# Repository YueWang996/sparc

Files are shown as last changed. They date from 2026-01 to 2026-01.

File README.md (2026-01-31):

<h1 align="center">
  SPARC: Spine with Prismatic and Revolute Compliance for Quadruped Robots
  <br><br>
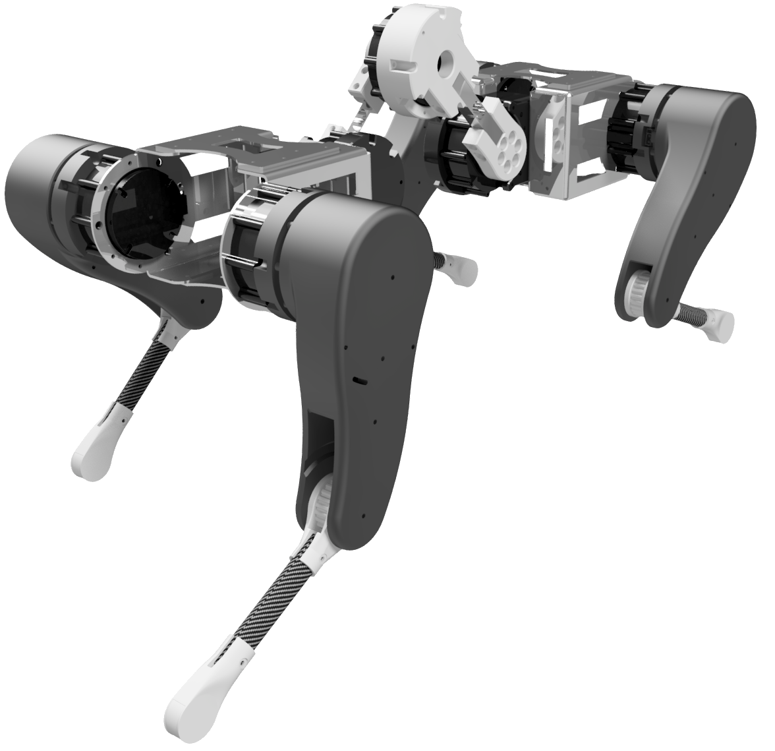
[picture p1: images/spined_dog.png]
SPARC Quadruped
  
  <br>
</h1>

<p align="center">
An open-source 3-DoF sagittal-plane spine module that combines revolute (pitch) and prismatic (axial) motion with programmable task-space impedance for quadruped robots. This repository provides complete hardware designs, circuit schematics, and MuJoCo simulation code for building and testing the SPARC system.
</p>

## Overview

<p align="center">
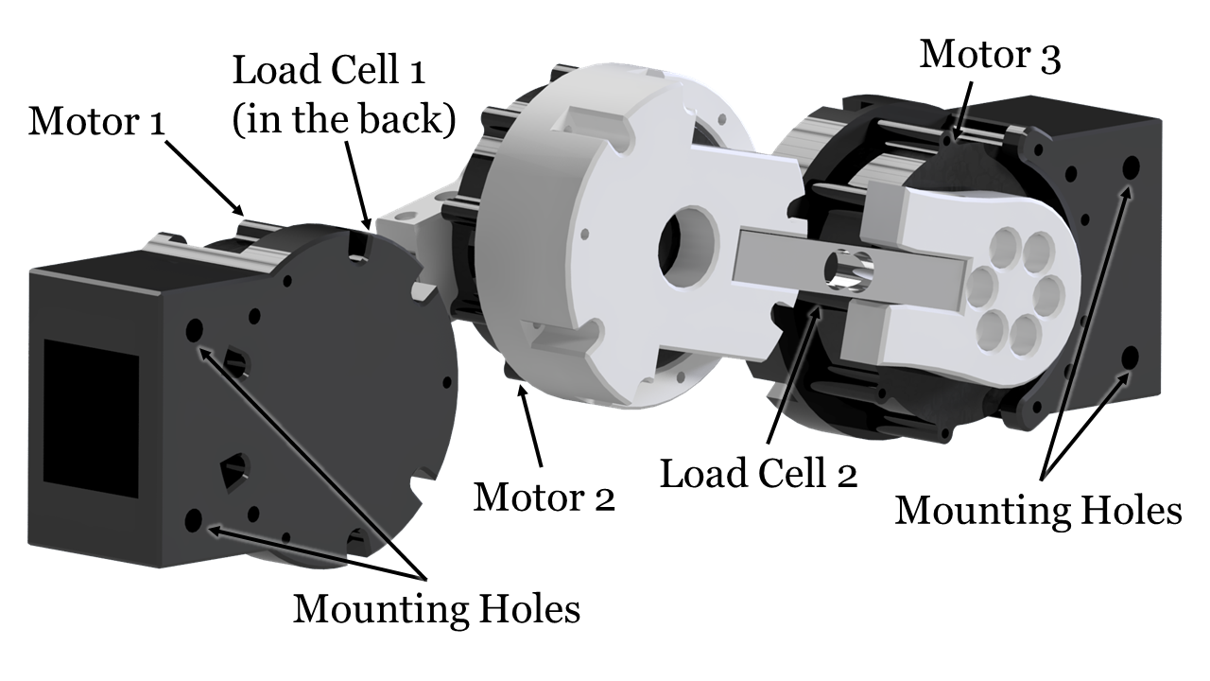
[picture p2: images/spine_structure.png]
SPARC Spine Structure
  
  <br>
  <em>SPARC spine structure with 3-DoF sagittal plane motion</em>
</p>

SPARC is a compact, self-contained spine module (1.26 kg) designed to mount between the fore and hind body segments of quadruped robots. The system integrates three torque-controlled actuators (Xiaomi Cybergear), a 1 kHz motion control board, and protected power electronics in a single package. A floating-base impedance controller with dynamics compensation renders tunable spring-damper behavior along horizontal, vertical, and rotational axes, enabling closed-loop control of both revolute and prismatic degrees of freedom with axis-selective compliance.

## Features

- **3-DoF Sagittal Spine**: Combined revolute (pitch) and prismatic (axial) motion for bio-inspired compliance
- **Task-Space Impedance Control**: Independently tunable stiffness and damping along horizontal, vertical, and rotational axes (validated range: 300-700 N/m horizontal stiffness with ≤1.5% error, R² ≥ 0.992)
- **High-Bandwidth Control**: 1 kHz control loop design with dynamics compensation and Stribeck friction modeling
- **Compact Design**: 1.26 kg package with three quasi-direct-drive actuators (12 N·m peak torque each)
- **Open-Source Hardware**: Complete CAD models and circuit schematics
- **MuJoCo Simulation**: Reference implementation and testing environment for spine compliance effects on locomotion

## Repository Structure

```
sparc/
├── hardware/
│   ├── cad_models_inventor/      # Autodesk Inventor CAD models and assemblies
│   └── circuit_altium_designer/  # Altium Designer circuit schematics and PCB layouts
├── mujoco_simulation/
│   ├── asset/                    # URDF/XML models and STL meshes
│   ├── spine_impedance_controller.py  # Task-space impedance controller implementation
│   ├── main_spine.py             # Basic spine simulation
│   ├── main_robot_raibert.py     # Quadruped bounding gait simulation
│   ├── dog_controller_raibert.py # Quadruped leg controller
│   └── mujoco_interface.py       # MuJoCo simulation interface
├── images/                       # Project images and diagrams
├── LICENSE                       # MIT License
└── README.md                     # This file
```

## Hardware Design

<p align="center">
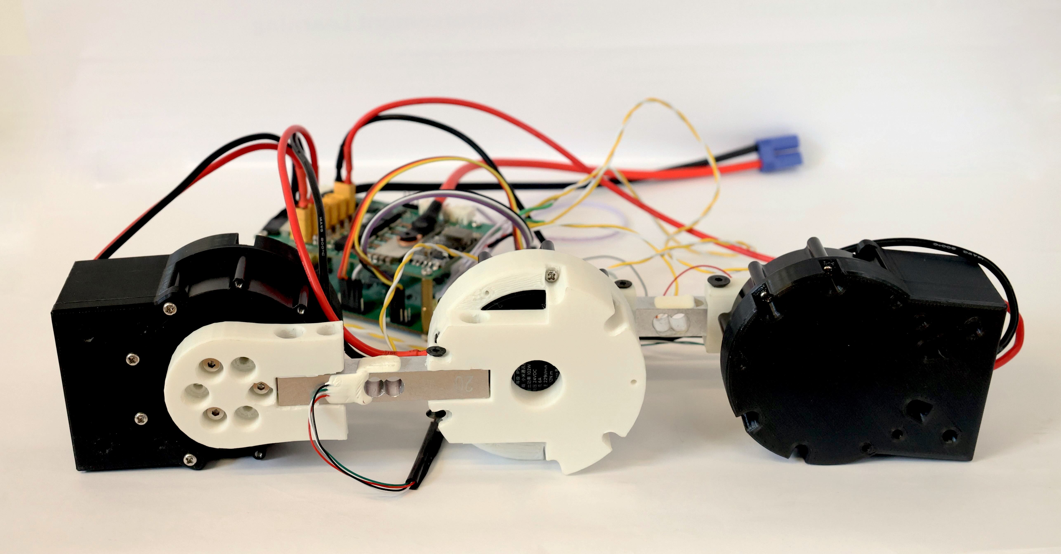
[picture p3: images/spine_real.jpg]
SPARC Hardware Prototype
  
  <br>
  <em>SPARC hardware prototype with integrated actuators and electronics</em>
</p>

The `hardware/` directory contains complete mechanical and electrical designs ready for fabrication:

- **CAD Models** ([cad_models_inventor/](hardware/cad_models_inventor/)): Autodesk Inventor files with complete spine assembly, 3D-printed links, and mounting interfaces for quadruped integration
- **Circuit Schematics** ([circuit_altium_designer/](hardware/circuit_altium_designer/)): Altium Designer project files for Motion Control Board (MCB) and Power Management Unit (PMU)

### Key Components

- **Actuators**: 3× Xiaomi Cybergear quasi-direct-drive motors (12 N·m peak torque, CAN bus interface)
- **Motion Control Board (MCB)**:
  - STM32F405RGT6 microcontroller (@168 MHz) (Note: this will be upgraded to STM32G473 shortly)
  - CAN transceiver for multi-actuator communication
  - Onboard 6-axis IMU for attitude estimation
  - USB interface for parameter tuning and debugging
- **Power Management Unit (PMU)**:
  - Input: 6S LiPo (22.2V nominal) or 24V bench supply
  - Over-current protection and thermal monitoring
  - Filtered power distribution to MCB and actuators
- **Sensing (Optional)**:
  - 2× load cells on central links for direct torque measurement
  - Magnetic encoders integrated in Cybergear actuators (14-bit resolution)
- **Structure**:
  - Lightweight 3D-printed links (PLA/PETG)
  - Mass distribution: 75% concentrated at actuators to minimize reflected inertia
  - Total spine mass: 1.26 kg

**Note**: Control software needs to be developed based on your specific requirements and the impedance control algorithms demonstrated in the simulation code.

## MuJoCo Simulation

The `mujoco_simulation/` directory provides simulation environments for testing and developing control algorithms for the SPARC spine.

### Available Simulations

1. **Basic Spine Simulation** ([main_spine.py](mujoco_simulation/main_spine.py))
   - Standalone spine characterization with manual displacement tests
   - Task-space impedance controller demonstration across 300-700 N/m stiffness range
   - Generates quasi-static force-displacement curves and dynamic step responses
   - Ideal for controller tuning and parameter exploration

2. **Quadruped Bounding Gait** ([main_robot.py](mujoco_simulation/main_robot.py))
   - Full 8-DoF quadruped robot with integrated SPARC spine
   - Bounding gait generator with configurable frequency, stride length, and step height
   - Real-time spine compliance adjustment during locomotion
   - Cost of transport optimization demonstrations
   - Supports terrain slope variation for performance analysis

### Simulation Features

- **Physics-accurate dynamics**: Task-space impedance control using batched CRBA/RNEA algorithms via [bard-pytorch-dynamics](https://github.com/YueWang996/bard-pytorch-dynamics)
- **Friction modeling**: Smooth Stribeck compensation for realistic low-velocity behavior
- **Complete robot models**: URDF files with inertial parameters and collision geometries
- **Real-time visualization**: Interactive MuJoCo viewer with parameter adjustment
- **Data logging**: CSV export for post-analysis and plotting

The simulation code provides a reference implementation of the impedance control algorithms that can be adapted for embedded systems.

## Getting Started

### Prerequisites

- Python 3.8+
- [MuJoCo](https://mujoco.org/) (for physics simulation)
- [bard-pytorch-dynamics](https://github.com/YueWang996/bard-pytorch-dynamics) (batched articulated robot dynamics solver)

### Installation

1. **Clone the repository**
   ```bash
   git clone https://github.com/YueWang996/sparc.git
   cd sparc
   ```

2. **Install MuJoCo**

   Follow the official [MuJoCo installation guide](https://mujoco.readthedocs.io/en/stable/programming/index.html#getting-started).

3. **Install bard-pytorch-dynamics**

   Follow the installation instructions at the [bard-pytorch-dynamics repository](https://github.com/YueWang996/bard-pytorch-dynamics.git):
   ```bash
   git clone https://github.com/YueWang996/bard-pytorch-dynamics.git
   cd bard-pytorch-dynamics
   # Follow the specific installation steps in that repository's README
   ```

4. **Install additional Python dependencies**
   ```bash
   pip install numpy scipy torch
   ```

### Usage

**Run the basic spine simulation:**
```bash
cd mujoco_simulation
python main_spine.py
```

This launches an interactive MuJoCo viewer where you can manually apply forces to the spine and observe the impedance response. Modify `kx`, `kz`, `kθ` (stiffness) and `dx`, `dz`, `dθ` (damping) parameters in the script to explore different compliance behaviors.

**Run the quadruped bounding gait simulation:**
```bash
cd mujoco_simulation
python main_robot_raibert.py
```

## Building Your Own SPARC

To replicate the hardware:

1. **3D Printing**: Export STL files from the Inventor assemblies in `hardware/cad_models_inventor/` and print using PLA or PETG
2. **PCB Fabrication**: Use the Altium Designer files in `hardware/circuit_altium_designer/` to generate Gerber files for PCB manufacturing
3. **Component Sourcing**:
   - 3× Xiaomi Cybergear motors (available from Xiaomi robotics distributors)
   - 2× Load cells (e.g., TAL220 10kg or similar)
   - STM32F405RGT6 microcontroller and supporting components (see BOM in circuit files. Note, the newer version is using STM32G473 for better performance)
   - 6S LiPo battery or 24V power supply
4. **Assembly**: Follow the CAD assembly structure for mechanical integration
5. **Control Software**: Develop your own control code using the simulation algorithms as reference. The [spine_impedance_controller.py](mujoco_simulation/spine_impedance_controller.py) provides the core impedance control implementation

For detailed build instructions, please refer to the documentation in the `hardware/` subdirectories.

## Performance Characteristics

The SPARC spine has been tested in both hardware benchtop experiments and MuJoCo simulations:

- **Static Stiffness**: Horizontal stiffness control from 300-700 N/m with high linearity (R² ≥ 0.992) across ±60 mm displacement range
- **Dynamic Response**: Tunable damping behavior from 0-40 N·s/m with predictable settling characteristics
- **Axis-Selective Compliance**: Independent control of horizontal, vertical, and rotational stiffness through task-space impedance control
- **Simulation Results**: Terrain-dependent optimal compliance settings:
  - **Downhill slopes**: Higher stiffness (1000-1500 N/m) reduces excessive pitch-down
  - **Flat terrain**: Moderate stiffness (800-1200 N/m) balances efficiency and stability
  - **Uphill slopes**: Lower stiffness (500-1000 N/m) enables elastic energy storage
  - **Optimal stride lengths (70-80 mm)**: Lowest cost of transport with 500-800 N/m stiffness and 8-20 N·s/m damping

These results suggest that adaptive spine compliance can reduce energy costs in quadruped locomotion across varying terrains and gaits.

<!-- ## Citation

If you use this work in your research, please cite:

```bibtex
@article{wang2026sparc,
  title={SPARC: Spine with Prismatic and Revolute Compliance for Quadruped Robots},
  author={Wang, Yue},
  journal={arXiv preprint arXiv:2510.01984},
  year={2026}
}
``` -->

## Applications and Integration

SPARC is designed as a modular component for quadruped robotics research. Potential applications include:

- **Locomotion Research**: Investigate the role of spinal compliance in gait transitions, energy efficiency, and stability
- **Terrain Adaptation**: Study real-time compliance tuning for varying surfaces and slopes
- **Bio-Inspired Robotics**: Explore mammalian spine mechanics in robotic systems
- **Agile Maneuvers**: Leverage spine compliance for jumping, landing, and rapid direction changes
- **Educational Platform**: Teach task-space impedance control and legged robot dynamics

The mounting interface is compatible with common quadruped platforms. Researchers can integrate SPARC by mounting it between fore and hind body segments using the provided bolt pattern.

## Troubleshooting and FAQ

**Q: The simulated spine oscillates excessively at low damping.**
A: Ensure the friction compensation parameters in [spine_impedance_controller.py](mujoco_simulation/spine_impedance_controller.py) match your system. Slight over-compensation can cause instability at `dx = 0`. Increase damping to `dx ≥ 2` N·s/m for stable operation.

**Q: How do I implement the controller on hardware?**
A: Use the simulation code in [spine_impedance_controller.py](mujoco_simulation/spine_impedance_controller.py) as a reference for implementing the task-space impedance control on your embedded system. The core algorithms (CRBA/RNEA, Jacobian computation, friction compensation) can be adapted to C/C++ for real-time execution.

**Q: Can I use different actuators?**
A: Yes, but you'll need to update the mechanical design to accommodate different motor dimensions and mounting patterns, and adapt your control software for different communication protocols.

**Q: What control loop frequency should I target?**
A: The design targets 1 kHz for effective bandwidth up to ~50-100 Hz depending on the commanded stiffness and system configuration.

## Contributing

Contributions are welcome! Areas where community input would be particularly valuable:

- Control software implementations for embedded systems
- Integration guides for specific quadruped platforms
- Additional simulation scenarios and benchmarks
- Experimental validation on different terrains
- Extended control strategies (MPC, reinforcement learning, etc.)

Please open an issue to discuss major changes before submitting pull requests.

## License

This project is licensed under the MIT License - see the [LICENSE](LICENSE) file for details.

<!-- ## Contact

For questions or collaboration opportunities:
- Open an issue in this repository
- GitHub: [@YueWang996](https://github.com/YueWang996) -->

## Acknowledgments

This work is supported by the School of Electronic and Computer Science (ECS), University of Southampton.

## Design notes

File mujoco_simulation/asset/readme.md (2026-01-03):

# Asset Files Documentation

This directory contains robot model files in two different formats for different purposes.

## File Overview

### URDF Files (for bard-pytorch-dynamics library)

URDF (Unified Robot Description Format) files are used with the bard-pytorch-dynamics library for solving robot dynamics problems.

#### `spine.urdf`
- **Purpose**: Defines the spine unit as a standalone component
- **Usage**: Use this file when you need to simulate or analyze the spine mechanism in isolation
- **Library**: bard-pytorch-dynamics

#### `spined_dog.urdf`
- **Purpose**: Defines a quadruped dog robot with the spine integrated into its body
- **Usage**: Use this file for full-body dynamics simulation with the spine attached to the dog's body
- **Library**: bard-pytorch-dynamics
- **Note**: This model includes full inertia properties for all body parts

#### `spined_dog_spine_dyn.urdf`
- **Purpose**: Defines a quadruped dog robot with the spine integrated, but with simplified leg dynamics
- **Usage**: Use this file when you want to focus on spine dynamics while ignoring leg inertia for computational simplicity
- **Library**: bard-pytorch-dynamics
- **Key Difference**: The spine is attached to the main body of the dog (which retains full inertia since the body is heavy), but the leg inertia is ignored for simplification

### XML Files (for MuJoCo simulation)

XML files are used for MuJoCo (Multi-Joint dynamics with Contact) physics simulation engine.

#### `spine.xml`
- **Purpose**: Defines the spine unit as a standalone component for MuJoCo simulation
- **Usage**: Use this file when simulating the spine mechanism in MuJoCo
- **Physics Engine**: MuJoCo

#### `spined_dog.xml`
- **Purpose**: Defines a quadruped dog robot with the spine integrated for MuJoCo simulation
- **Usage**: Use this file for full-body physics simulation of the spined dog in MuJoCo
- **Physics Engine**: MuJoCo

## Summary Table

| File | Format | Model Type | Purpose | Library/Engine |
|---|---|---|---|---|
| `spine.urdf` | URDF | Spine only | Spine dynamics analysis | bard-pytorch-dynamics |
| `spined_dog.urdf` | URDF | Full dog + spine | Full dynamics with complete inertia | bard-pytorch-dynamics |
| `spined_dog_spine_dyn.urdf` | URDF | Dog + spine (simplified) | Spine-focused dynamics with simplified legs | bard-pytorch-dynamics |
| `spine.xml` | XML | Spine only | Spine MuJoCo simulation | MuJoCo |
| `spined_dog.xml` | XML | Full dog + spine | Full MuJoCo simulation | MuJoCo |

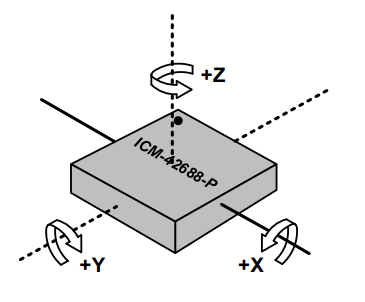
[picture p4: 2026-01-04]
hardware/circuit_altium_designer/motion_control_board/imu.jpg

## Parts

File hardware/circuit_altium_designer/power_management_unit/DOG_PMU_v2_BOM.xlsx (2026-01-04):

Comment | Description | Designator | Footprint | LibRef | Quantity
22uF | VJ1210Y104MXCAT | C1, C2, C3, C4 | C1210 | Capacitor | 4
0.1uF |  | C5, C16, C17, C18, C19 | C0603 | Capacitor | 5
330pF |  | C6 | C0603 | Capacitor | 1
1.5nF |  | C7 | C0603 | Capacitor | 1
10uF | VJ1210Y104MXCAT | C8, C10, C11, C12, C13, C15 | C1210 | Capacitor | 6
1uF | VJ1210Y104MXCAT | C9, C14 | C0603 | Capacitor | 2
5.0SMDJ28A |  | D1 | SMA(DO-214AC) | Diode_Schottky | 1
MBRS3100T3G | Schottky Diodes & Rectifiers 3A 100V | D2 | SMA(DO-214AC) | Diode_Schottky | 1
红灯 0603 | 发光二极管 | D3, D4 | 0603_LED_S1 | 0603 红灯 | 2
B7B-XH-A__LF__SN_ | Connector | J1 | SHDR7W64P0X250_1X7_1990X575X700P | B7B-XH-A__LF__SN_ | 1
5263-3AW |  | J2 | 5264-3AW | 5263-3AW | 1
XH_2.54mm_1x2P |  | J3, J4, J10 | XH2.54mm1x2P弯插 | XH_2.54mm_1x2P | 3
XT30UPB | https://item.taobao.com/item.htm?id=607162270928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 | J5, J6, J8, J9, J11, J12 | XT30UPB | XT30UPB | 6
Header1x4 |  | J7 | Header 1x4p | Header1x4 | 1
KEY_3*4 | C707339 | KEY1 | KEY_3*4 | KEY_3*4 | 1
CSD19536KTT | 100-V N-Channel NexFET™ Power MOSFET | Q1, Q2, Q3, Q4 | KTT0002A | NMOSFET | 4
178kΩ |  | R1 | R0603 | Resistor | 1
5.49kΩ |  | R2 | R0603 | Resistor | 1
10kΩ |  | R3, R12, R13, R14, R15, R16, R17, R32, R33 | R0603 | Resistor | 9
68.1kΩ |  | R4, R5, R6, R7, R8, R9 | R0603 | Resistor | 6
28kΩ |  | R10 | R0603 | Resistor | 1
56kΩ |  | R11 | R0603 | Resistor | 1
1mΩ | CHSA2512R0010F | R18, R19, R20, R21, R22 | 2512_R | Resistor | 5
470kΩ |  | R23, R24 | R0603 | Resistor | 2
1kΩ |  | R25 | R0603 | Resistor | 1
10Ω |  | R26, R27, R28, R29 | R0603 | Resistor | 4
NTCS0805E3103JMT | THERMISTOR NTC 10KOHM 3570K 0805 | R30, R31 | NTCS0805_VIS | CMP-02404-000004-2 | 2
10k |  | R34, R35, R36, R37, R38, R39 | R0603 | Resistor | 6
TPS2492PW | The TPS2492 and TPS2493 are easy-to-use, positive high voltage, 14-pin Hotswap Controller | U1 | PW0014A_N | TPS2492PW | 1
TPS5450_module | https://item.taobao.com/item.htm?id=678523742086&spm=a1z0d.6639537&sku_properties=1627207:1665065280 | U2 | TPS5450_module | TPS5450_module | 1
AMS1117-3.3 | C347222 | U3 | SOT-223 | AMS1117-3.3 | 1
STM32C011F6P6 | No Description Available | U4 | TSSOP20_STM | STM32C011F6P6 | 1

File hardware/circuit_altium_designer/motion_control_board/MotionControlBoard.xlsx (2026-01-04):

Comment | Description | Designator | Footprint | LibRef | Quantity
2.2uF |  | C1, C4 | C0603 | Capacitor | 2
20pF |  | C2, C3 | C0603 | Capacitor | 2
0.1uF |  | C5, C7, C8, C9, C10, C11, C12, C13, C16, C17, C19, C20 | C0603 | Capacitor | 12
1uF |  | C6, C14, C15 | C0603 | Capacitor | 3
10nF |  | C18 | C0603 | Capacitor | 1
LED | 发光二极管 | D1, D2, D3, D4 | 0603_LED_S1 | 0603 红灯 | 4
Drill_M3 |  | Drill1, Drill2, Drill3, Drill4 | Drill_M_3 | Drill_M3 | 4
XH_2.54mm_1x2P |  | J1, J5, J6, J8, J9, J10, J11, J12, J13 | XH2.54mm1x2P弯插 | XH_2.54mm_1x2P | 9
Header1x4 |  | J2, J3, J4, J16 | Header 1x4p | Header1x4 | 4
1*5P | C145957 | J7 | 1.0T-5P | 插座 1*5P 卧贴 | 1
5263-3AW |  | J14, J15 | 5264-3AW | 5263-3AW | 2
Header1x20 |  | J17 | Header1x20 | Header1x20 | 1
Header2*4 | C124386 | J18 | Header2*4 | Header2*4 | 1
BOOT | C707339 | KEY1 | KEY_3*4 | KEY_3*4 | 1
nRST | C707339 | KEY2 | KEY_3*4 | KEY_3*4 | 1
10kΩ |  | R1, R3 | R0603 | Resistor | 2
330Ω |  | R2, R15 | R0603 | Resistor | 2
2.2kΩ |  | R4, R5, R11, R12, R13, R14 | R0603 | Resistor | 6
22Ω |  | R6, R7, R8, R9, R10 | R0603 | Resistor | 5
120Ω |  | R16, R17 | R0603 | Resistor | 2
STM32F405RGT6 | Integrated Circuit | U1 | QFP50P1200X1200X160-64N | STM32F405RGT6TR | 1
AMS1117-3.3 | C347222 | U2 | SOT-223 | AMS1117-3.3 | 1
ICM-42688-P | Integrated Circuit | U3 | IIM42352 | ICM-42688-P | 1
ME6211C33M5G-N | C82942 | U4 | SOT-23-5 | ME6211C33M5G-N | 1
SN65HVD232DR | C30530 | U5, U6 | SOIC-8_150mil | SN65HVD232DR | 2
8MHz ±10ppm 20pF YSX530GA | Crystal or Oscillator | Y1 | X503212MSB2GI | X503212MSB2GI | 1

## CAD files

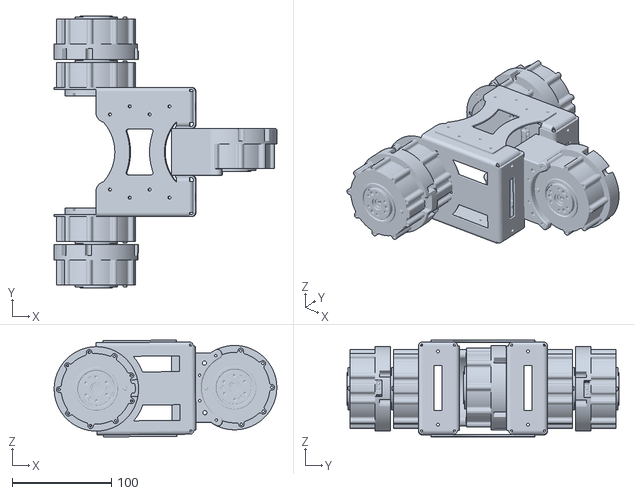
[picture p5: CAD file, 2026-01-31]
mujoco_simulation/asset/meshes/hind_body.stl
224.3 x 274.0 x 97.7

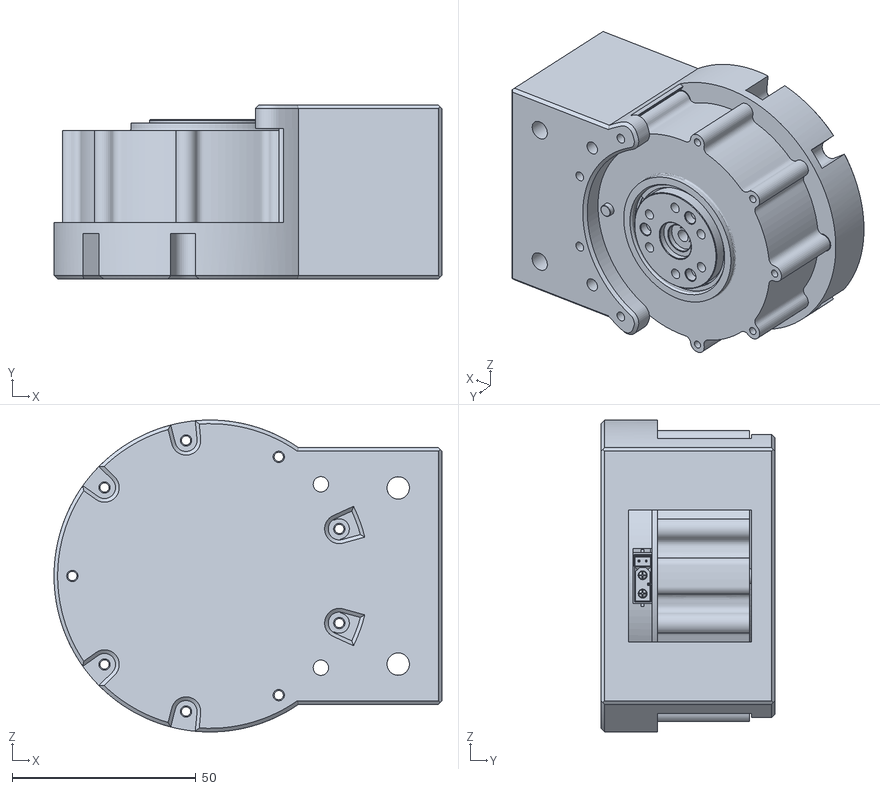
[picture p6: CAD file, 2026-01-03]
mujoco_simulation/asset/meshes/front_spine.stl
105.7 x 47.5 x 85.0

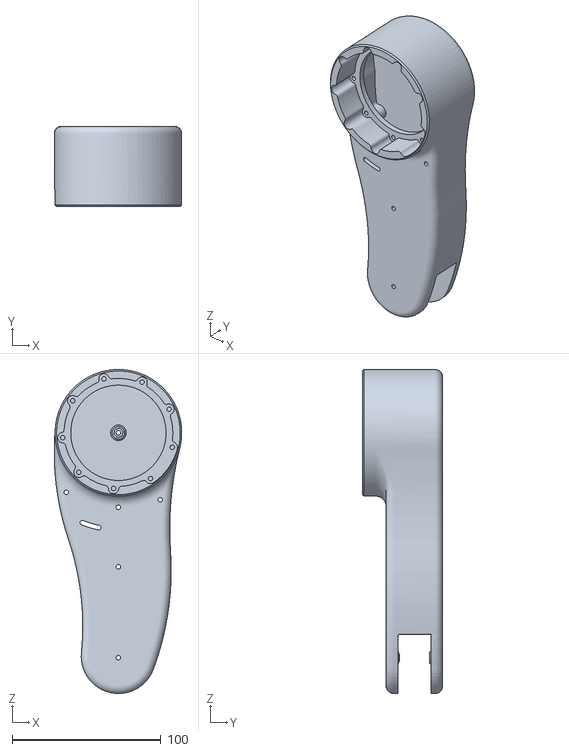
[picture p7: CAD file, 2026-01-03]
mujoco_simulation/asset/meshes/hind_left_leg_upper.stl
85.6 x 54.0 x 217.5

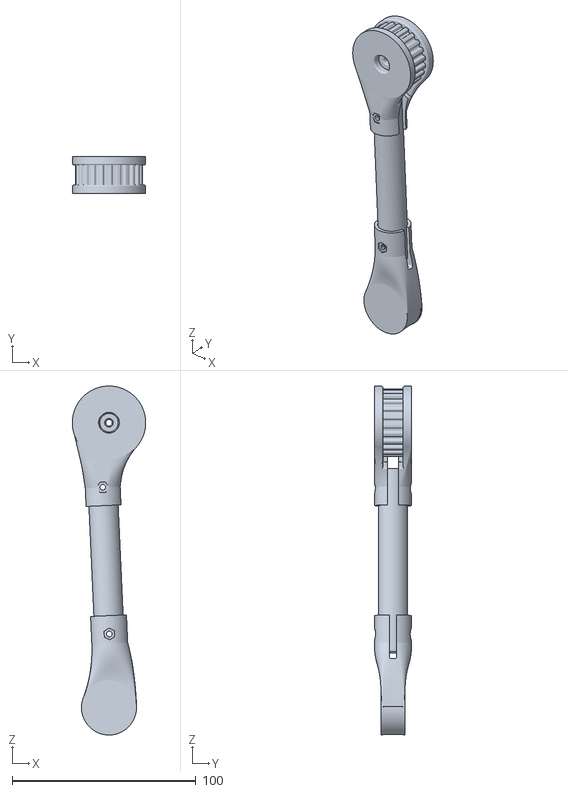
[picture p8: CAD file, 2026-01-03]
mujoco_simulation/asset/meshes/front_leg_lower.stl
40.0 x 20.1 x 190.1

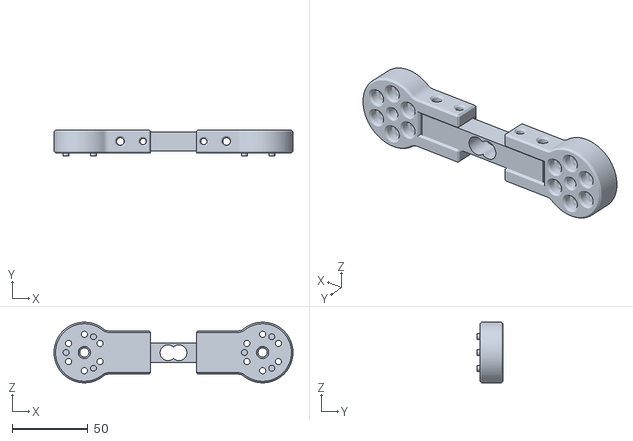
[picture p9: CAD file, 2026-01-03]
mujoco_simulation/asset/meshes/front_mid_spine.stl
157.5 x 17.0 x 40.0

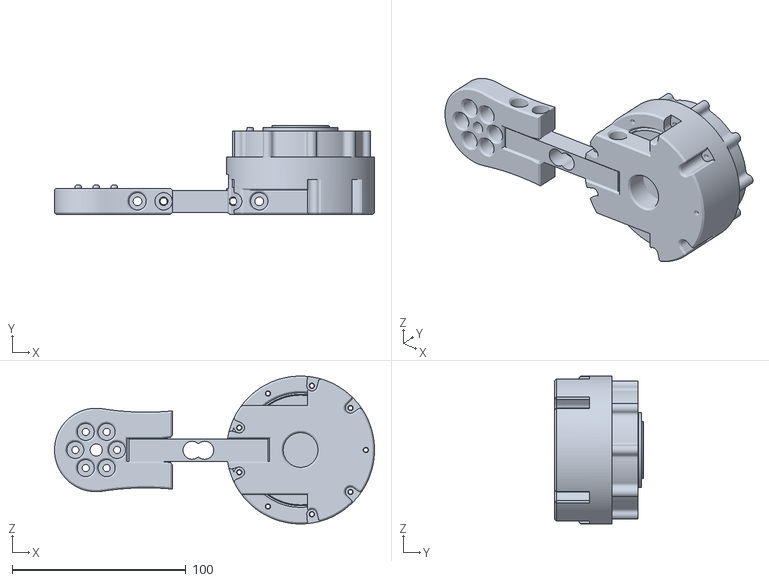
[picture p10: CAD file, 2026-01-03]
mujoco_simulation/asset/meshes/hind_mid_spine.stl
184.0 x 51.0 x 85.0

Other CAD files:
hardware/circuit_altium_designer/power_management_unit/busbar2.dwg
hardware/circuit_altium_designer/power_management_unit/bus_bar_v3.dwg
mujoco_simulation/asset/meshes/simplify_front_body.stl
hardware/circuit_altium_designer/power_management_unit/boardoutline.dwg
mujoco_simulation/asset/meshes/front_body.stl
hardware/circuit_altium_designer/power_management_unit/busbar.dwg
mujoco_simulation/asset/meshes/simplify_hind_body.stl
mujoco_simulation/asset/meshes/front_left_leg_upper.stl
mujoco_simulation/asset/meshes/hind_leg_lower.stl
mujoco_simulation/asset/meshes/hind_right_leg_upper.stl
mujoco_simulation/asset/meshes/front_right_leg_upper.stl
mujoco_simulation/asset/meshes/hind_spine.stl
hardware/cad_models_inventor/leg_connector.ipt

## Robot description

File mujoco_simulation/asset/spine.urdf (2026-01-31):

<?xml version="1.0"?>
<robot name="spine">

  <!-- Link: hind_spine (base link) -->
  <link name="hind_body">
    <inertial>
      <origin xyz="0 0 0" rpy="0 0 0"/>
      <mass value="0.377"/>
      <inertia ixx="0.0001832" ixy="0" ixz="0" iyy="0.0003327" iyz="0" izz="0.0002337"/>
    </inertial>
    <visual>
      <origin xyz="0 0 0" rpy="0 0 0"/>
      <geometry>
        <mesh filename="meshes/hind_spine.stl" scale="0.001 0.001 0.001"/>
      </geometry>
    </visual>
    <!-- <collision>
      <origin xyz="0 0 0" rpy="0 0 0"/>
      <geometry>
        <mesh filename="meshes/hind_spine.stl" scale="0.001 0.001 0.001"/>
      </geometry>
    </collision> -->
  </link>

  <joint name="joint_hind_body" type="revolute">
    <parent link="hind_body"/>
    <child link="hind_spine"/>
    <origin xyz="0.00454 -0.017638872 0" rpy="0 0 0"/>
    <axis xyz="0 1 0"/>
    <limit lower="-10" upper="10" effort="12" velocity="100"/>
    <dynamics damping="0.0" friction="0.0"/>
  </joint>

  <!-- Link: hind_spine -->
  <link name="hind_spine">
    <inertial>
      <origin xyz="0.109455866 0.014797864 0" rpy="0 0 0"/>
      <mass value="0.399"/>
      <inertia ixx="0.0001953" ixy="0" ixz="0" iyy="0.0005357" iyz="0" izz="0.0004759"/>
    </inertial>
    <visual>
      <origin xyz="0 0 0" rpy="0 0 0"/>
      <geometry>
        <mesh filename="meshes/hind_mid_spine.stl" scale="0.001 0.001 0.001"/>
      </geometry>
    </visual>
    <!-- <collision>
      <origin xyz="0 0 0" rpy="0 0 0"/>
      <geometry>
        <mesh filename="meshes/hind_mid_spine.stl" scale="0.001 0.001 0.001"/>
      </geometry>
    </collision> -->
  </link>

  <joint name="joint_hind_spine" type="revolute">
    <parent link="hind_spine"/>
    <child link="front_spine"/>
    <origin xyz="0.1175 0.036 0" rpy="0 0 0"/>
    <axis xyz="0 1 0"/>
    <limit lower="-10" upper="10" effort="12" velocity="100"/>
    <dynamics damping="0.0" friction="0.0"/>
  </joint>

  <!-- Link: front_spine -->
  <link name="front_spine">
    <inertial>
      <origin xyz="0.05875 0.0073 0" rpy="0 0 0"/>
      <mass value="0.052"/>
      <inertia ixx="0.00001" ixy="0" ixz="0" iyy="0.000084358" iyz="0" izz="0.000082313"/>
    </inertial>
    <visual>
      <origin xyz="0 0 0" rpy="0 0 0"/>
      <geometry>
        <mesh filename="meshes/front_mid_spine.stl" scale="0.001 0.001 0.001"/>
      </geometry>
    </visual>
    <!-- <collision>
      <origin xyz="0 0 0" rpy="0 0 0"/>
      <geometry>
        <mesh filename="meshes/front_mid_spine.stl" scale="0.001 0.001 0.001"/>
      </geometry>
    </collision> -->
  </link>

  <joint name="joint_front_spine" type="revolute">
    <parent link="front_spine"/>
    <child link="front_body"/>
    <origin xyz="0.1175 0 0" rpy="0 0 0"/>
    <axis xyz="0 1 0"/>
    <limit lower="-10" upper="10" effort="12" velocity="100"/>
    <dynamics damping="0.0" friction="0.0"/>
  </joint>

  <!-- Link: front_body -->
  <link name="front_body">
    <inertial>
      <origin xyz="0.00454141 -0.017638872 0" rpy="0 0 0"/>
      <mass value="0.377197524"/>
      <inertia ixx="0.0001832" ixy="0" ixz="0" iyy="0.0003327" iyz="0" izz="0.0002337"/>
    </inertial>
    <visual>
      <origin xyz="0 0 0" rpy="0 0 0"/>
      <geometry>
        <mesh filename="meshes/front_spine.stl" scale="0.001 0.001 0.001"/>
      </geometry>
    </visual>
    <!-- <collision>
      <origin xyz="0 0 0" rpy="0 0 0"/>
      <geometry>
        <mesh filename="meshes/front_spine.stl" scale="0.001 0.001 0.001"/>
      </geometry>
    </collision> -->
  </link>

  <joint name="joint_spine_ee" type="fixed">
    <parent link="front_body"/>
    <child link="spine_end_effector"/>
    <origin xyz="0.00454141 0 0" rpy="0 0 0"/>
  </joint>

  <link name="spine_end_effector">
    <inertial>
      <origin xyz="0 0 0" rpy="0 0 0"/>
      <mass value="0.001"/>
      <inertia ixx="0.00001" ixy="0" ixz="0" iyy="0.00001" iyz="0" izz="0.00001"/>
    </inertial>
  </link>
</robot>

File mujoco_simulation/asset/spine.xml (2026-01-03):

<mujoco model="spine">
    <compiler angle="radian" meshdir="./meshes/"/>
    <option timestep="1e-3" iterations="10" tolerance="1e-10" impratio="10" gravity="0 0 -9.81" solver="CG" cone="elliptic"/>
    <asset>
        <mesh name="hind_body" file="hind_spine.stl" scale="0.001 0.001 0.001"/>
        <mesh name="hind_spine" file="hind_mid_spine.stl" scale="0.001 0.001 0.001"/>
        <mesh name="front_spine" file="front_mid_spine.stl" scale="0.001 0.001 0.001"/>
        <mesh name="front_body" file="front_spine.stl" scale="0.001 0.001 0.001"/>

        <texture builtin="gradient" height="256" rgb1=".9 .9 1." rgb2=".2 .3 .4" type="skybox" width="256"/>
        <texture builtin="checker" height="512" name="texplane" rgb1=".2 .3 .4" rgb2=".1 0.15 0.2" type="2d" width="512"/>
        <material name="floorplane" reflectance="0.2" texrepeat="5 5" texture="texplane" texuniform="true"/>
    </asset>

    <default>
        <default class="spined_dog_defaults">
            <joint axis="0 1 0" range="-10 10" actuatorfrcrange="-12 12" damping="0.0" frictionloss="0.0"/>
        </default>
    </default>

    <worldbody>
        <geom name="floor0" pos="0. 0. 0." size="3 3 .125" type="plane" condim="3" material="floorplane"/>
        <light directional="true" ambient="0.2 0.2 0.2" diffuse="0.8 0.8 0.8" specular="0.3 0.3 0.3" castshadow="false" pos="0 0 4" dir="0 0 -1" name="light0"/>

        <!-- ROOT BODY with FREEJOINT for floating base -->
        <body name="hind_body" pos="0 0 0.5" quat="1 0 0 0" childclass="spined_dog_defaults">
            <inertial pos="0 0 0" mass="0.377" diaginertia="0.0001832 0.0003327 0.0002337"/>
            <!-- FREEJOINT: Provides 6-DOF floating base (3 translation + 3 rotation) -->
            <!-- <freejoint name="root_joint"/> -->
            <geom pos="0 0 0" type="mesh" contype="0" conaffinity="0" group="1" density="0" mesh="hind_body"/>
            <!-- <geom pos="0 0 0" type="mesh" mesh="hind_body"/> -->
            <!-- LINK 2 -->
            <body name="hind_spine" pos="0.00454 -0.017638872 0">
                <inertial pos="0.109455866 0.014797864 0" mass="0.399" diaginertia="0.0001953 0.0005357 0.0004759"/>
                <!-- JOINT 1: First revolute joint -->
                <joint name="joint_hind_spine" pos="0 0 0"/>
                <geom pos="0 0 0" type="mesh" contype="0" conaffinity="1" group="1" density="0" mesh="hind_spine" condim="1"/>
                <!-- <geom pos="0 0 0" type="mesh" mesh="hind_mid_spine"/> -->

                <!-- LINK 3 -->
                <body name="front_spine" pos="0.1175 0.036 0">
                    <inertial pos="0.05875 0.0073 0" mass="0.052" diaginertia="0.0000036976 0.000084358 0.000082312887603"/>
                    <!-- JOINT 2: Second revolute joint -->
                    <joint name="joint_front_spine" pos="0 0 0"/>
                    <geom pos="0 0 0" type="mesh" contype="0" conaffinity="1" group="1" density="0" mesh="front_spine" condim="1"/>
                    <!-- <geom pos="0 0 0" type="mesh" mesh="front_spine"/> -->

                    <!-- LINK 4 -->
                    <body name="front_body" pos="0.1175 0 0">
                        <inertial pos="0.00454141 -0.017638872 0" mass="0.377197524" diaginertia="0.0001832 0.0003327 0.0002337"/>
                        <!-- JOINT 3: Third revolute joint -->
                        <joint name="joint_front_body" pos="0 0 0"/>
                        <geom pos="0 0 0" type="mesh" contype="0" conaffinity="1" group="1" density="0" mesh="front_body" condim="1"/>
                        <!-- <geom pos="0 0 0" type="mesh" mesh="front_body"/> -->
                    </body>
                </body>
            </body>
        </body>
    </worldbody>

    <actuator>
        <!-- Only actuate the 3 spine joints, NOT the freejoint -->
        <motor joint="joint_hind_spine" name="motor_hind_spine" gear="1" ctrllimited="true" ctrlrange="-12.0 12.0"/>
        <motor joint="joint_front_spine" name="motor_front_spine" gear="1" ctrllimited="true" ctrlrange="-12.0 12.0"/>
        <motor joint="joint_front_body" name="motor_front_body" gear="1" ctrllimited="true" ctrlrange="-12.0 12.0"/>
    </actuator>

    <sensor>
        <!-- Joint positions -->
        <jointpos name="pos_joint_hind_spine" joint="joint_hind_spine"/>
        <jointpos name="pos_joint_front_spine" joint="joint_front_spine"/>
        <jointpos name="pos_joint_front_body" joint="joint_front_body"/>

        <!-- Joint velocities -->
        <jointvel name="vel_joint_hind_spine" joint="joint_hind_spine"/>
        <jointvel name="vel_joint_front_spine" joint="joint_front_spine"/>
        <jointvel name="vel_joint_front_body" joint="joint_front_body"/>

        <!-- Joint torques -->
        <jointactuatorfrc name="torque_joint_hind_spine" joint="joint_hind_spine" noise="0.0"/>
        <jointactuatorfrc name="torque_joint_front_spine" joint="joint_front_spine" noise="0.0"/>
        <jointactuatorfrc name="torque_joint_front_body" joint="joint_front_body" noise="0.0"/>

        <!-- Optional: Sensors for floating base state -->
        <framepos name="base_position" objtype="body" objname="hind_body"/>
        <framequat name="base_orientation" objtype="body" objname="hind_body"/>
        <framelinvel name="base_linear_velocity" objtype="body" objname="hind_body"/>
        <frameangvel name="base_angular_velocity" objtype="body" objname="hind_body"/>
    </sensor>
</mujoco>

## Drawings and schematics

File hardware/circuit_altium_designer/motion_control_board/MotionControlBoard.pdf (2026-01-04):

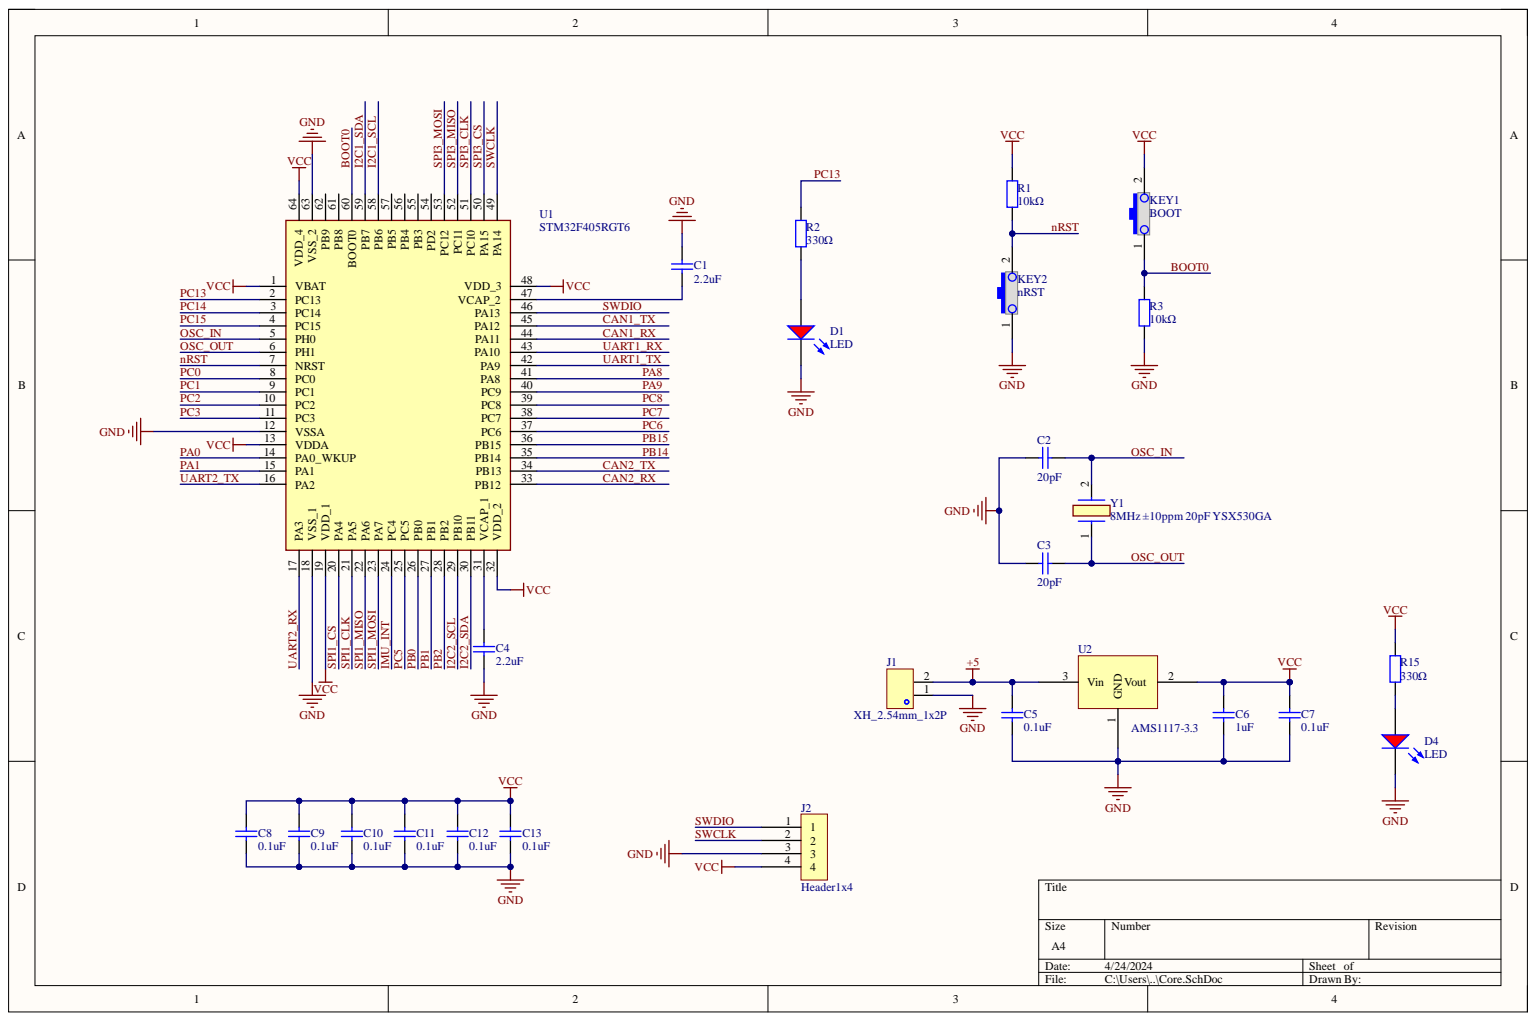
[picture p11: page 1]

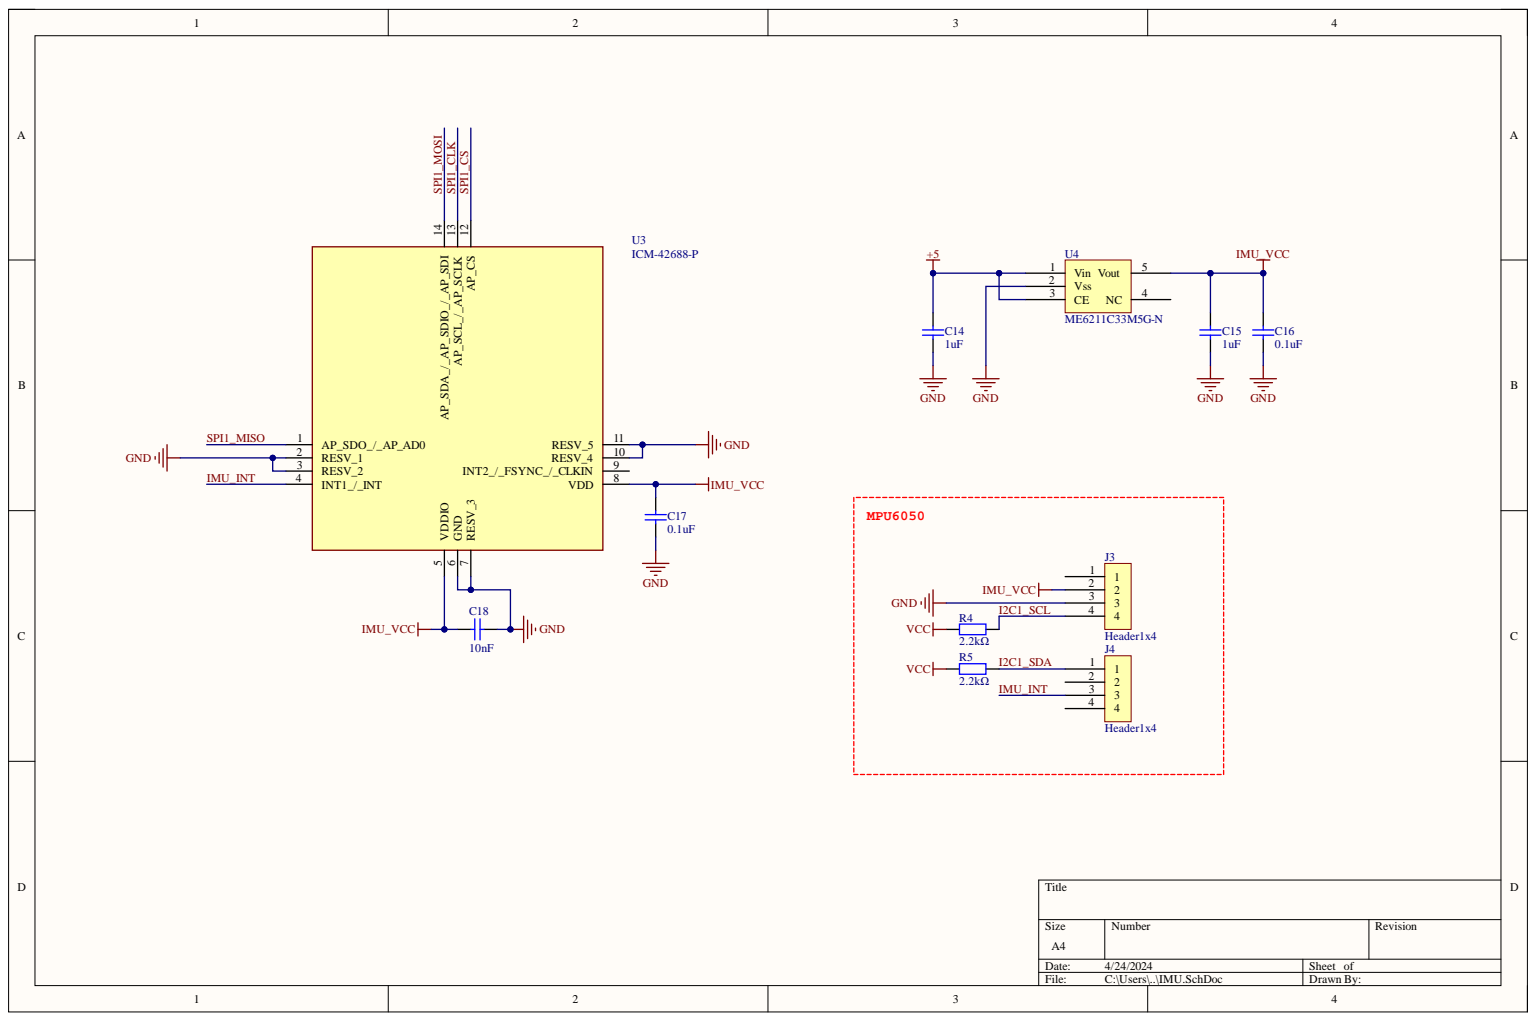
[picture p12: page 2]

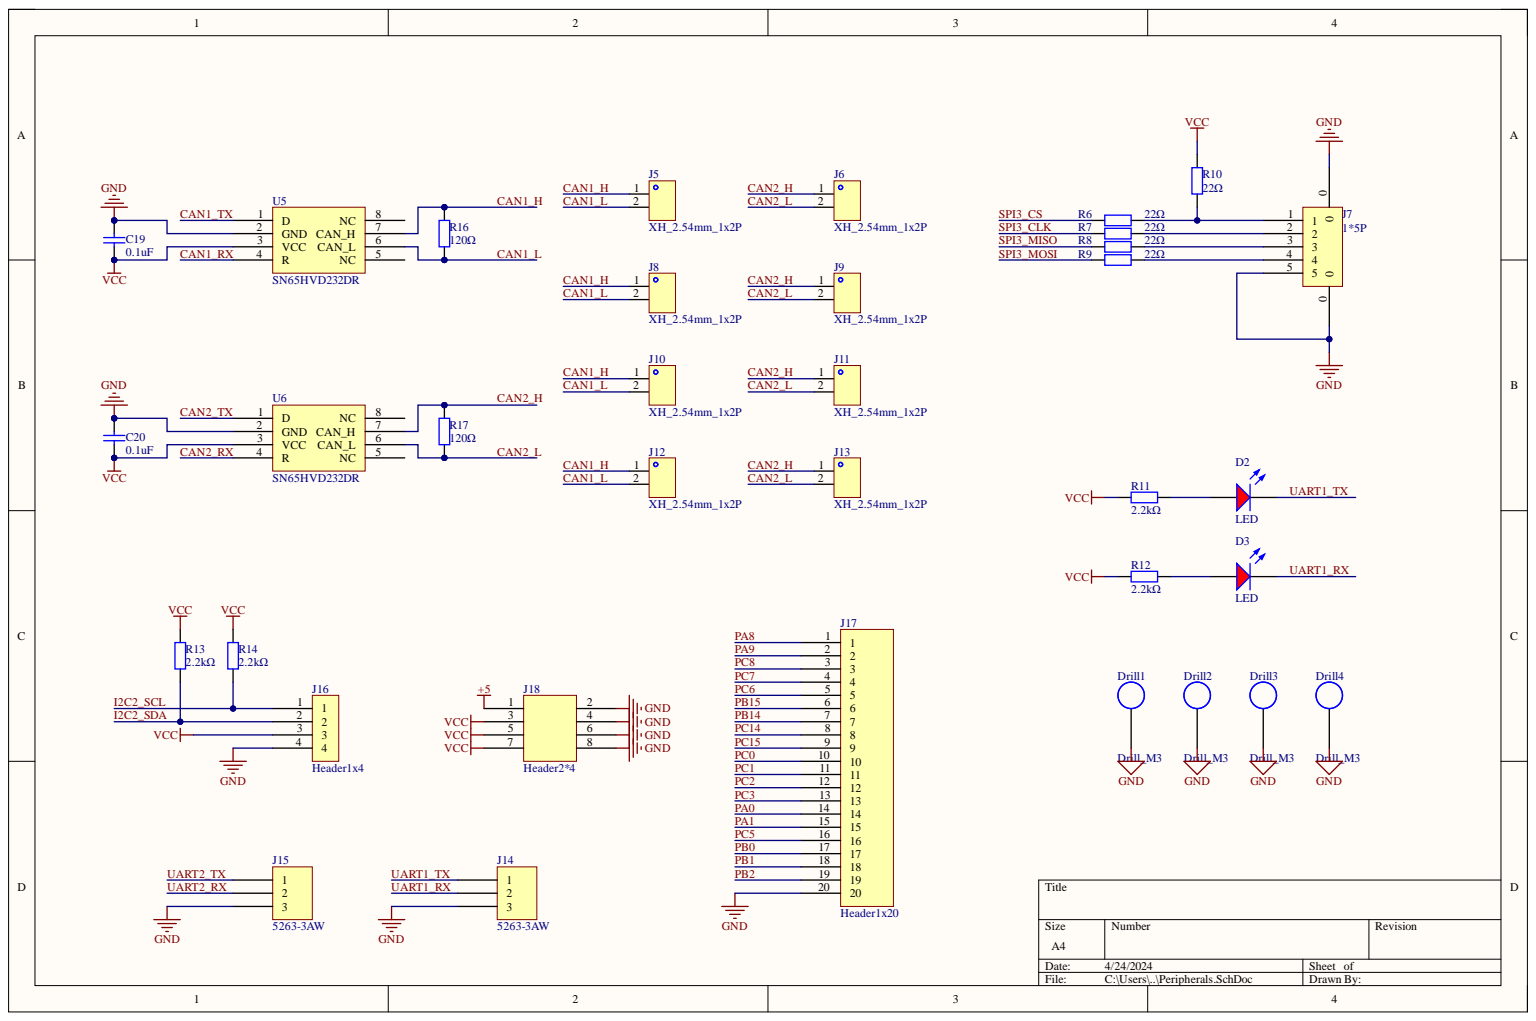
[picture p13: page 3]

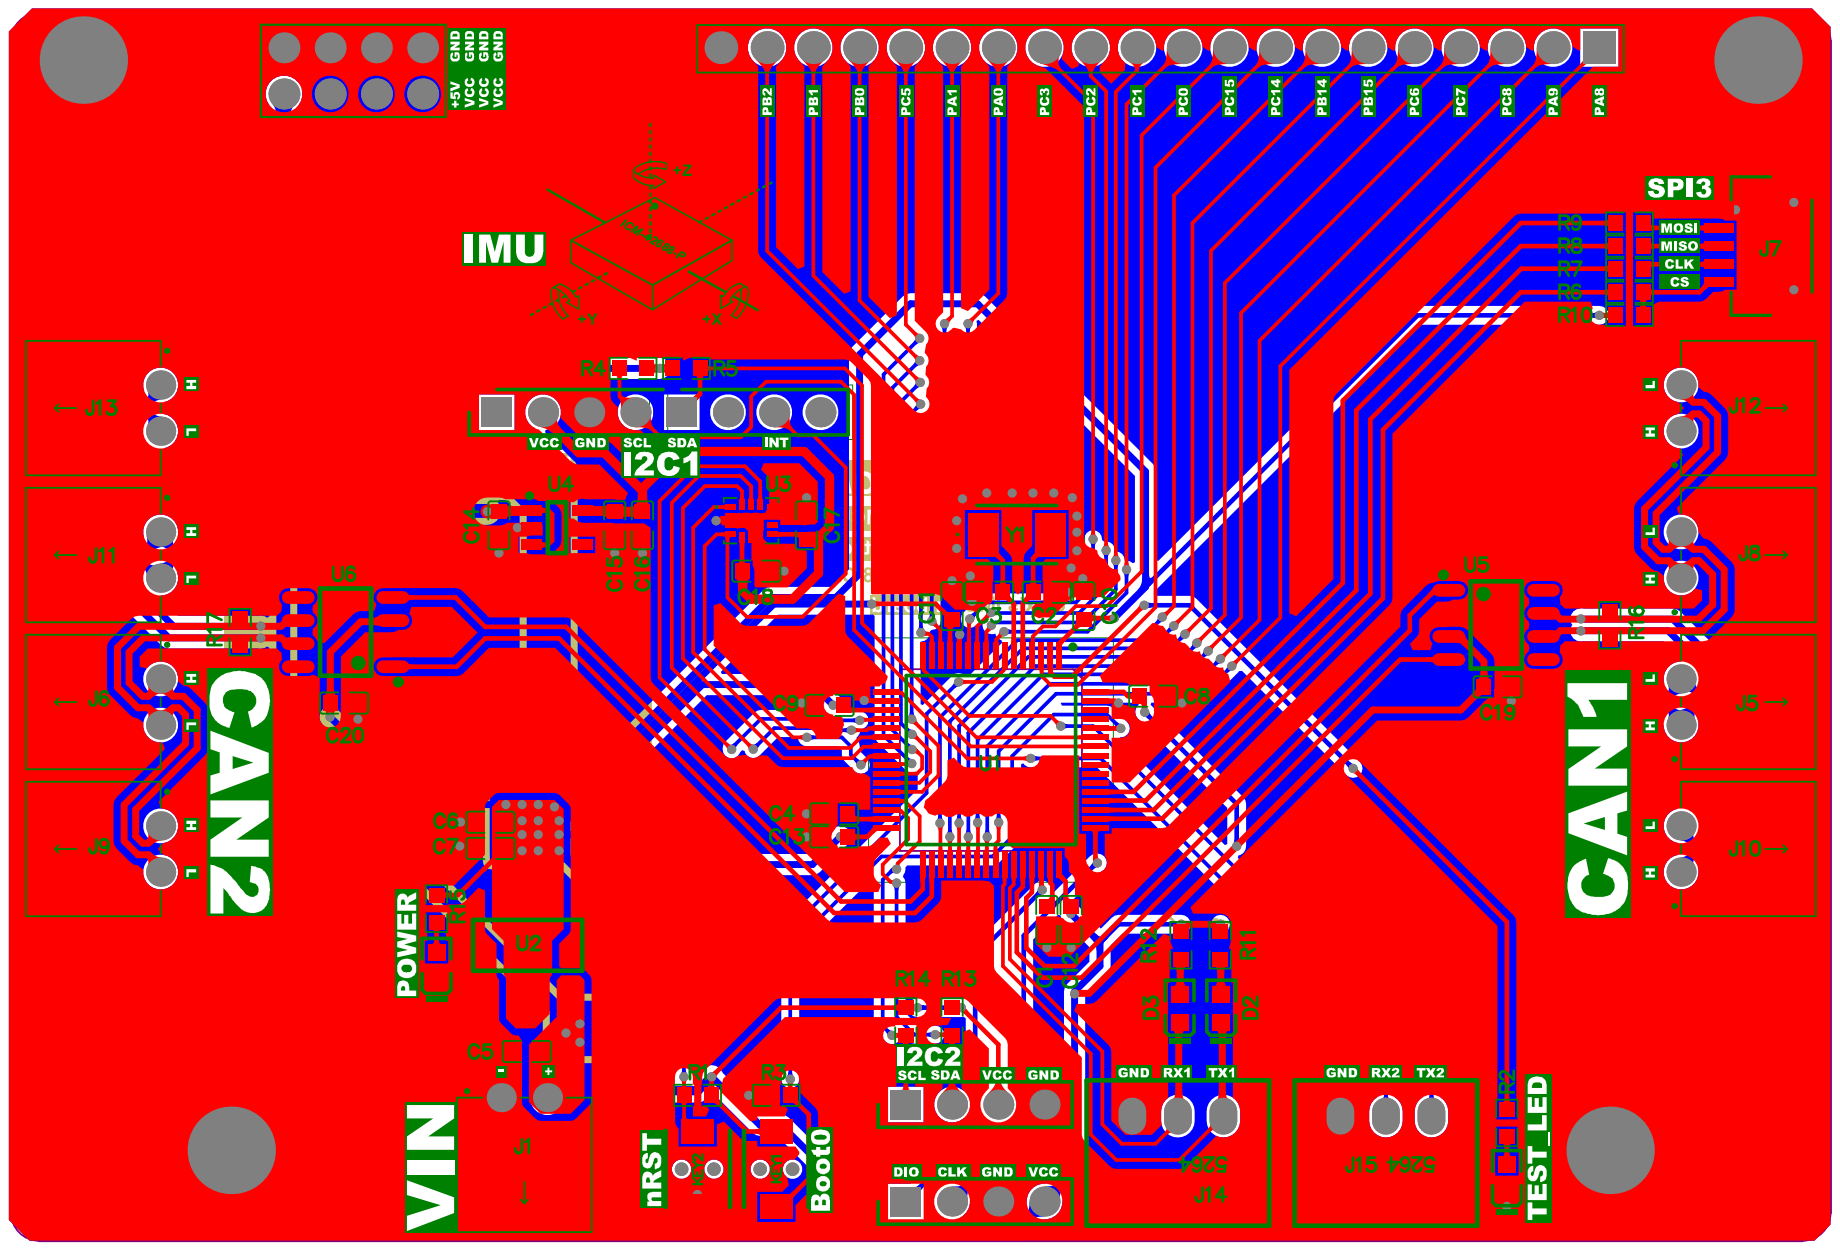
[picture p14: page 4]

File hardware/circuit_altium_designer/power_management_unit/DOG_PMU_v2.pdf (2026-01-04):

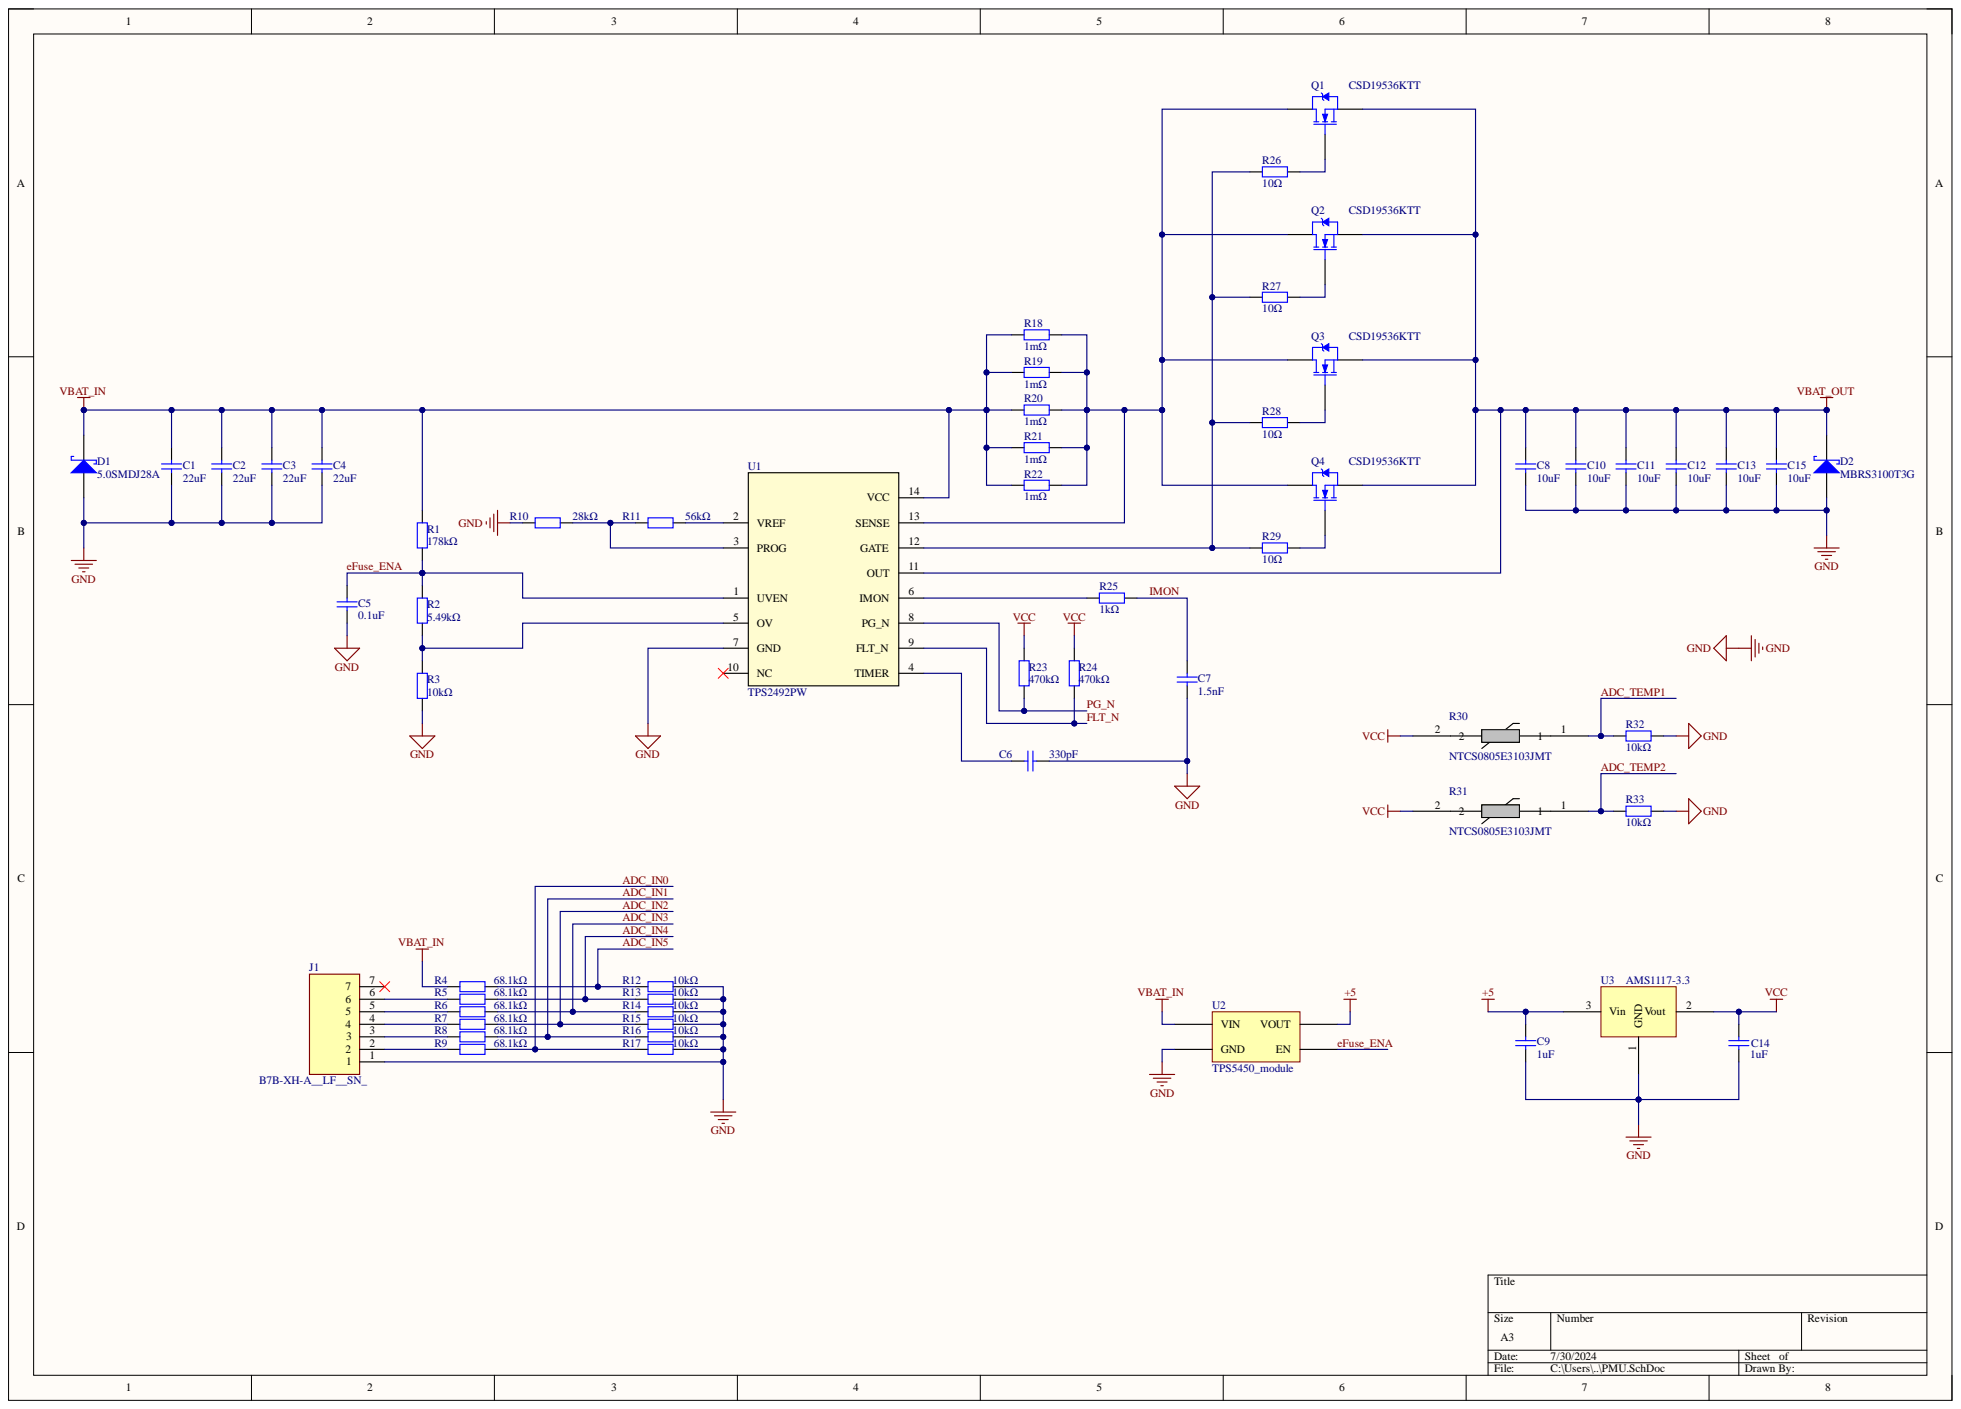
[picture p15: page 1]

3 R 8 | 68.1k Ω | | R16 | 10k Ω
2 R 9 | 68.1k Ω | R17 | | 10k Ω

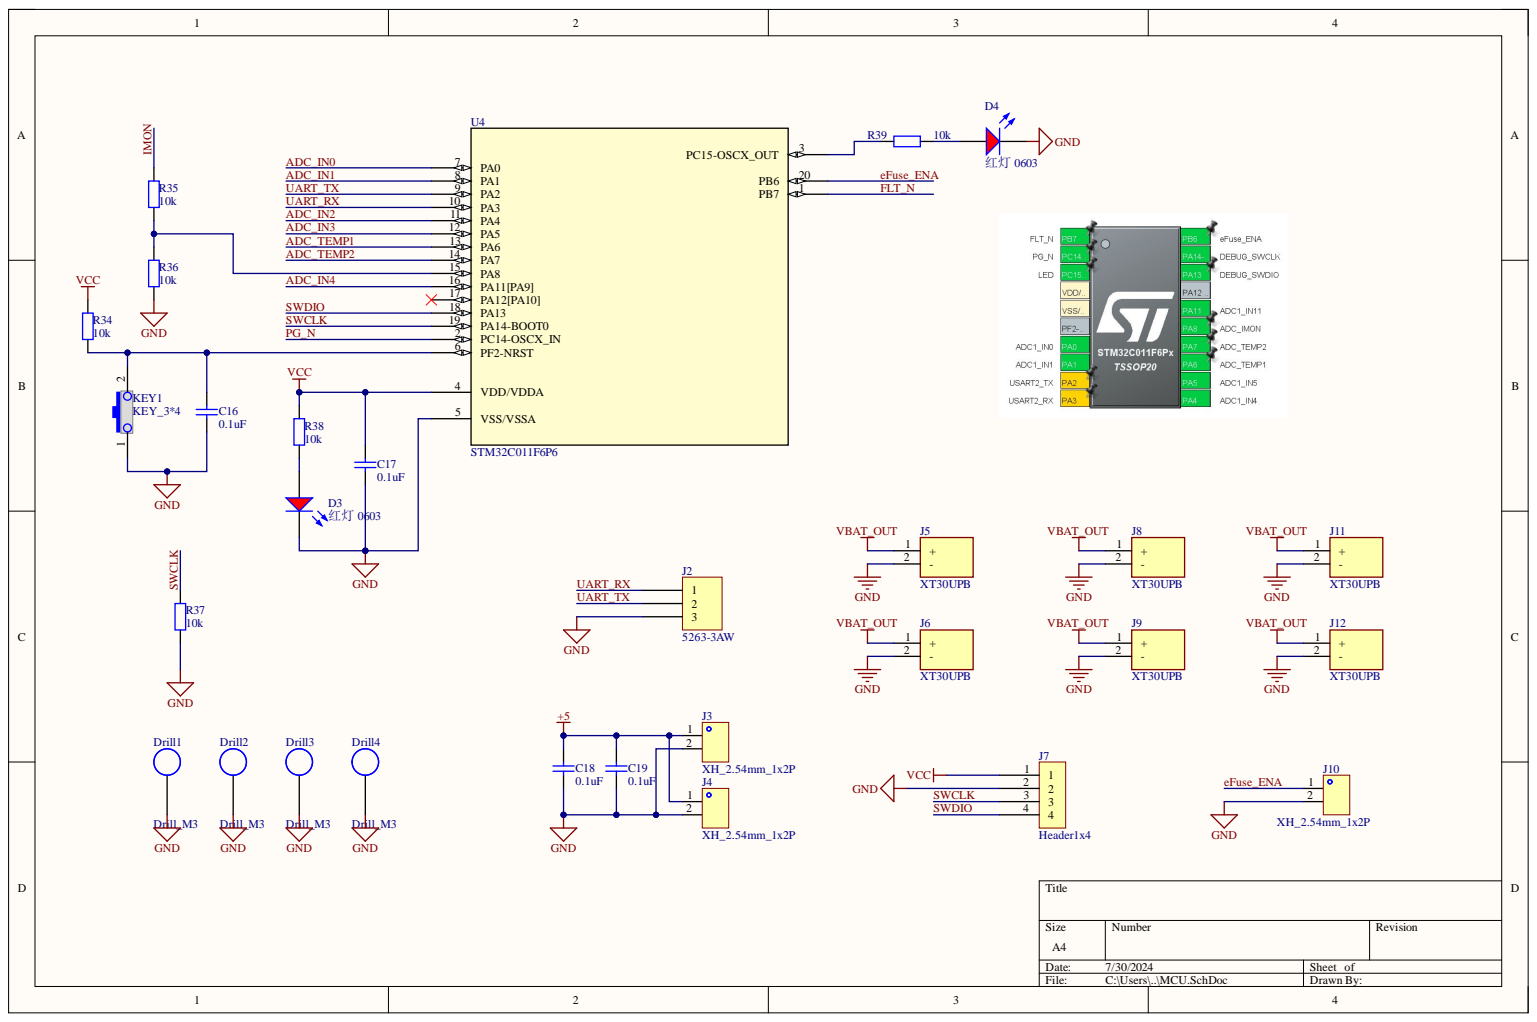
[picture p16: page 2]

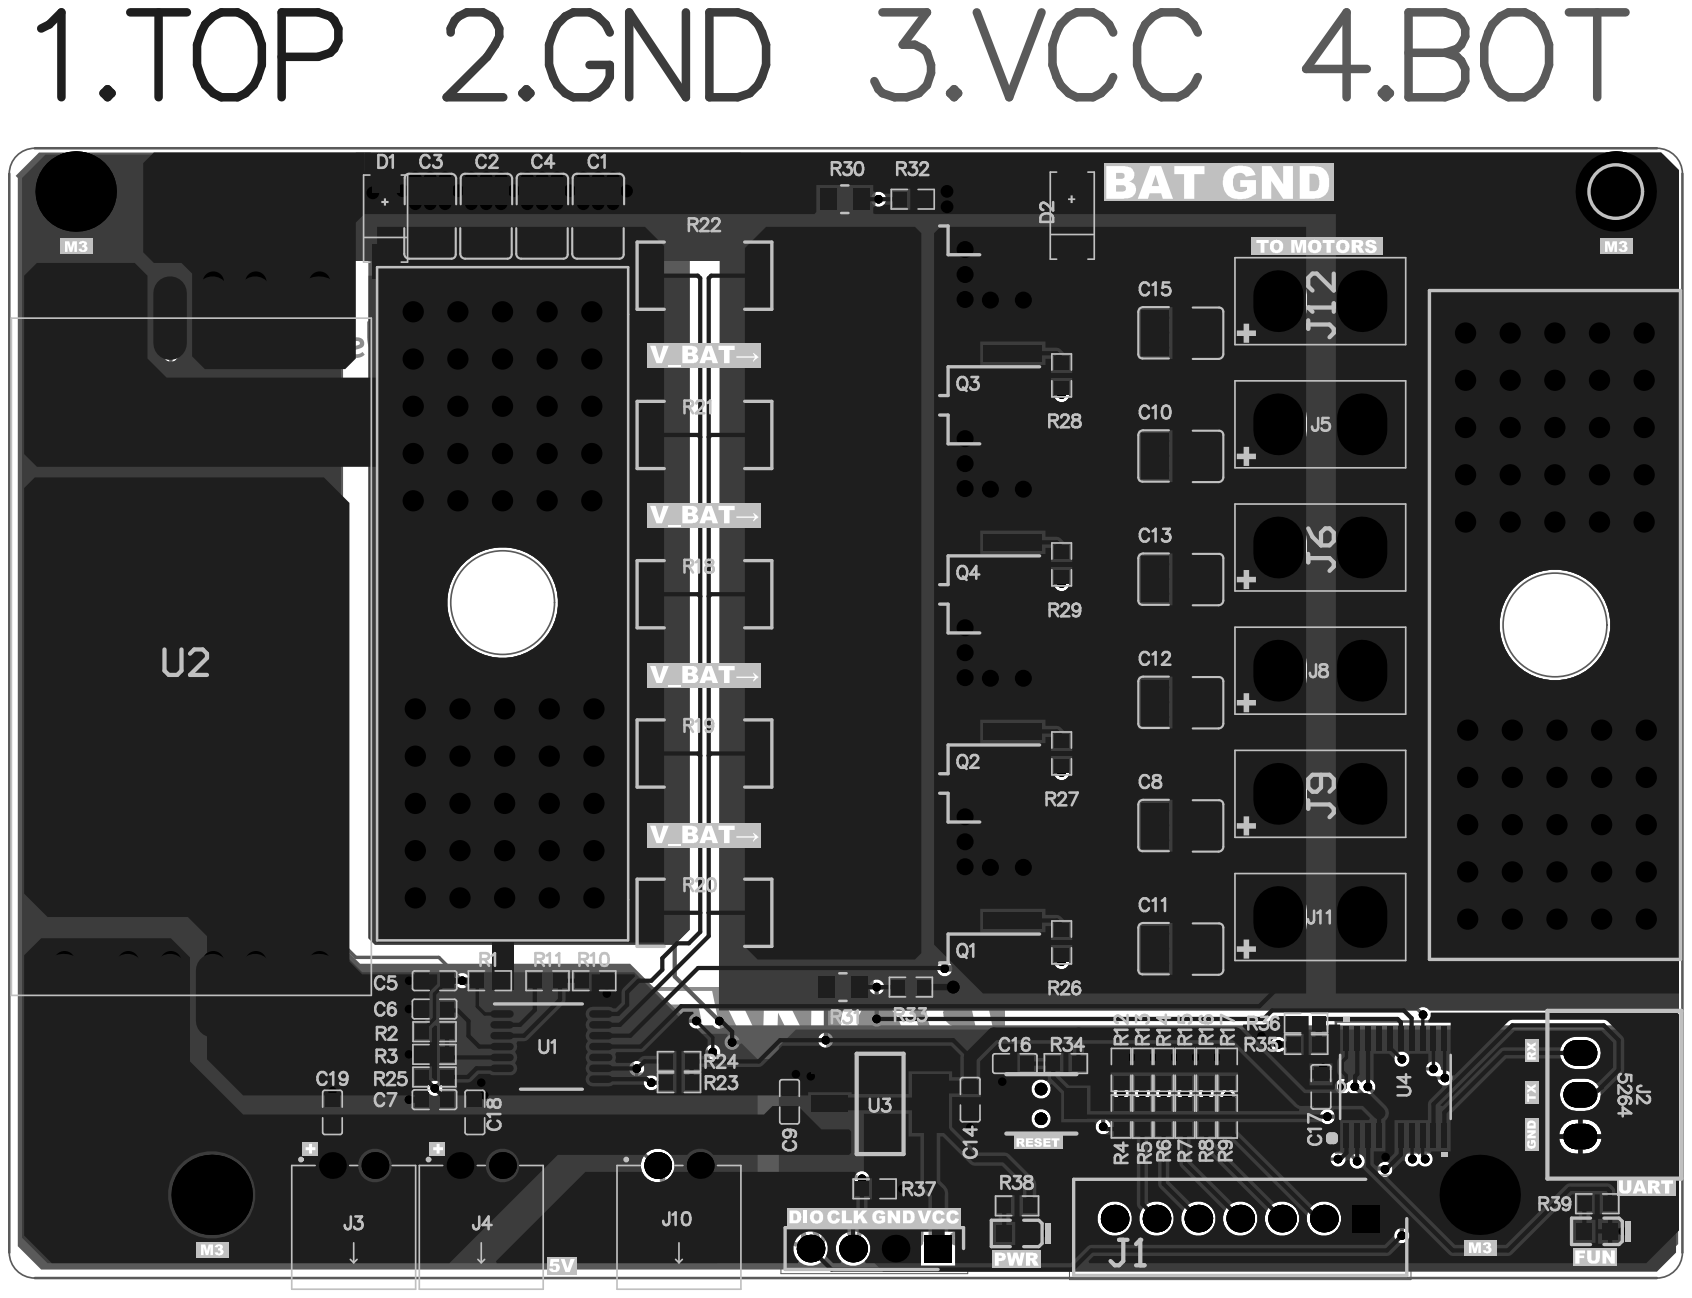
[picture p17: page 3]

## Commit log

2026-01-03 project source file uploaded and readme updated
    [front_left_leg_upper.stl, front_leg_lower.stl, front_mid_spine.stl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]
2026-01-04 PCB design is added
    [Core.SchDoc, DOG_PMU_v2.PrjPcb, DOG_PMU_v2_BOM.xlsx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]
2026-01-19 Add MuJoCo interface and spine impedance controller implementations
    - Introduced `MuJoCoInterface` for interacting with MuJoCo simulations, including methods for getting and setting body poses, joint positions, velocities, and torques.
    - Implemented `SpineImpedanceController` for regulating the position and orientation of the spine in relation to a base link, including methods for computing task-space positions and gain matrices.
    - Added necessary imports and structured the code for better readability and maintainability.
2026-01-31 feat: Implement Raibert controller for spined dog simulation
    - Added `main_robot_raibert.py` to integrate the Raibert controller with the MuJoCo simulation.
    - Enhanced `MuJoCoSimulation` class with custom control logic for legged locomotion.
    - Updated `main_spine.py` to use relative paths for model and URDF files.
    - Modified `SpineImpedanceController` to support geometric constraints with soft barrier forces.
    - Introduced methods for calculating foot contact forces in `MuJoCoInterface`.
    - Adjusted gains and desired positions in the spine controller for improved performance.
    [spine.urdf, spined_dog_locked_spine.xml, spined_dog_locked_spine_lightweight.xml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]
2026-01-31 Remove ignored files from repository
    [Core.SchDoc, DOG_PMU_v2.PrjPcb, DOG_PMU_v2_BOM.xlsx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]
2026-01-31 docs: Update README with STM32G473 upgrade note and citation section comment
